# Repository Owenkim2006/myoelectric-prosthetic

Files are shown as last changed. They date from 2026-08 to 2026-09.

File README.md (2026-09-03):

# Myoelectric Prosthetic Hand

**BME 261 Final Project** · University of Waterloo · August 2026  

---

## Overview

This project develops a functional myoelectric prosthetic hand for transradial amputees performing demanding tasks. The system converts microvolt-level surface EMG signals into mechanical grip control through three integrated subsystems: a 7-stage analog front-end, non-blocking C++ firmware, and a dog clutch locking mechanism.

Benchmarked against the Cybathlon "Carry Bottles" task — gripping weighted bottles, placing them into a crate, and transporting the load.

---

## System Architecture

```
Surface EMG Electrodes
        │
        ▼
┌─────────────────────────────────────┐
│     7-Stage Analog Front-End        │
│                                     │
│  1. AD623 INA (gain ~101)           │
│  2. Sallen-Key HPF (48 Hz)          │
│  3. Sallen-Key LPF (400 Hz)         │
│  4. Isolation Buffer                │
│  5. Non-Inverting Amp (gain 11)     │
│  6. Peak Envelope Detector          │
│  7. Schmitt Trigger Comparator      │
│                                     │
│  Total gain: ~1,111×                │
└──────────────────┬──────────────────┘
                   │  Digital trigger (0–5V)
                   ▼
        Arduino Microcontroller
        (Non-blocking state machine)
                   │
                   ▼
          Position Servo Motor
                   │
                   ▼
            Dog Clutch
     (locks finger transmission shafts)
                   │
                   ▼
      Passive Spring-Loaded Fingers
```

---

## Electrical Subsystem

The analog front-end processes raw surface EMG signals (10μV–5mV) through a cascaded 7-stage single-supply architecture.

### Signal Chain

| Stage | Component | Function | Key Parameters |
|---|---|---|---|
| 1 | AD623 INA | Differential amplification, CM rejection | Gain ~101, R_G = 1kΩ |
| 2 | Sallen-Key HPF | Remove motion artifacts, electrode drift | f_c ≈ 48 Hz, C = 33nF, R = 1MΩ / 10kΩ |
| 3 | Sallen-Key LPF | Remove high-frequency noise | f_c ≈ 400 Hz, R = 20kΩ, C = 12nF / 33nF |
| 4 | Buffer (follower) | Isolation — prevent impedance loading | Unity gain |
| 5 | Non-inverting amp | Secondary voltage gain | Gain = 11, R_in = 10kΩ, R_f = 100kΩ |
| 6 | Peak detector | Rectify AC bursts to DC envelope | Active diode-capacitor |
| 7 | Schmitt trigger | Clean binary output to Arduino | Hysteretic comparator |

**Total system gain: ~1,111×**

### Virtual Ground

A buffered voltage divider (2× 10kΩ) creates a stable Vcc/2 reference, enabling single-supply operation. The reference automatically scales with battery voltage — no recalibration needed when switching between lab supply and battery.

### Power

- Lab: regulated DC supply (5V)
- Portable: dual 4×AA packs in parallel (~6V, doubled current capacity)

### Frequency Response

Measured passband: 48–400 Hz. Overdamped filter design produces gradual roll-off at corner frequencies.

---

## Firmware

Written in C++ on Arduino. Non-blocking time-domain state machine — no `delay()` calls.

### State Machine

```
         ┌─────────────────┐
         │      IDLE       │
         └────────┬────────┘
                  │ Edge detected on input pin
                  ▼
         ┌─────────────────┐
         │  BURST ACTIVE   │◄──────────────┐
         │  (timing burst) │               │ Still toggling
         └────────┬────────┘               │
                  │ Duration ≥ 500ms        │
                  ▼                        │
         ┌─────────────────┐               │
         │    ACTUATE      │               │
         │  Toggle servo   │               │
         │  Set lock flag  │               │
         └────────┬────────┘               │
                  │ Signal static > 400ms   │
                  ▼                        │
         ┌─────────────────┐               │
         │  RESET LOCKOUT  │───────────────┘
         │  Clear flags    │
         └─────────────────┘
```

### Key Parameters

| Parameter | Value | Purpose |
|---|---|---|
| `activityWindow` | 500 ms | Minimum contraction duration — rejects twitches and noise spikes |
| `quietTimeout` | 400 ms | Rest period required before next trigger |
| Servo open | 135° | Dog clutch disengaged — fingers free |
| Servo closed | 150° | Dog clutch engaged — fingers locked |

### Why these values?

The 500ms window was chosen to eliminate false triggers from static shocks, brief muscle twitches, and electrical noise while remaining responsive enough for intentional grips. The 400ms quiet timeout prevents rapid re-triggering during a single sustained contraction. Servo angles are software-clamped to prevent mechanical binding and the 2.5A stall current observed near 170°.

---

## Mechanical Subsystem

- **Fingers:** Two interconnected phalange sections (base + top) coordinated by sprockets, chains, and gears
- **Actuation:** Passive spring loading — fingers open when pressed against object geometry
- **Locking:** Dog clutch controlled by position servo — mechanically retains grip with zero steady-state motor current
- **Structure:** Laser-cut plywood with box-joint connections, aluminum axles

### Finger Movement

When the hand contacts an object, friction and reaction forces passively open the fingers to conform to the object geometry. The internal spring tension closes the fingers around the object. On muscle activation, the servo engages the dog clutch, locking the transmission shafts and holding the grip position.

---

## Repository Structure

```
myoelectric-prosthetic/
  firmware/
    prosthetic_control.ino     # Arduino C++ state machine
    flowchart.png              # Firmware flowchart
  electrical/
    bodeplots.png             # Bode plots
    schematic.png              # Full system schematic
    falstad_diagram.txt                # Falstad simulation export
  pcb/
    gerbers/                   # Fabrication files
    prosthetic_pcb.kicad_pcb   # KiCad board file
    prosthetic.kicad_sch       # KiCad schematic
    bom.csv                    # Bill of materials
  mechanical/
    presentation.pdf
  docs/
    BME261_Final_Report.pdf    # Full project report
    bill_of_materials.pdf      # List of parts
```

---

## Running the Falstad Simulation

1. Open [Falstad Circuit Simulator](https://www.falstad.com/circuit/)
2. Click **File → Import from Text**
3. Paste the contents of `electrical/falstad/circuit.txt`
4. Press **Run** to simulate the signal conditioning pipeline

---

## Results

| Metric | Result |
|---|---|
| Signal passband | 48–400 Hz |
| Total analog gain | ~1,111× |
| EMG input range | 10μV–5mV |
| Output range | 0–5V (Arduino compatible) |
| Trigger delay | 500ms (intentional) |
| Servo travel | 135°–150° |
| Cybathlon task | Successfully demonstrated |
| PCB | 2-layer through-hole, 0.4mm signal / 0.8mm power traces |
| Ground | Solid B.Cu copper pour, thermal relief on all pads |
| DRC | 0 errors, 0 unconnected items |

---

## Limitations & Future Work

- **Materials:** PETG components and superglue connections loosened during testing. Future: engineering-grade heat-resistant materials, pinned dog clutch connection
- **Firmware:** 500ms window reduces responsiveness. Future: continuous ADC sampling with digital moving-average filter, shorter activation window
- **Electrical:** Hand-soldered perfboard susceptible to EMI and stray capacitance. Future: multi-layer SMD PCB, LDO regulator for analog supply, buck-boost for servo
- **Power:** Unregulated battery causes reference drift as charge depletes. Future: dedicated LDO for analog front-end
- **Mechanical:** Smooth plastic palm reduces friction on objects. Future: compliant grip surface material

---

## Built With

- **Electrical:** AD623, TL072/TL082 op-amps, discrete passives
- **Simulation:** [Falstad Circuit Simulator](https://www.falstad.com/circuit/)
- **PCB:** KiCad
- **Mechanical:** Autodesk Fusion 360, laser-cut plywood, PETG 3D printing
- **Firmware:** Arduino (C++)
- **Course:** BME 261 — Biomedical Design, University of Waterloo

---

## Authors

- Owen Kim — Electrical subsystem, firmware, PCB design
- Adithi Nagarajan — Mechanical subsystem
- Hilda Zhang — Mechanical subsystem

---

## License

MIT — free to use, adapt, and build on with attribution.

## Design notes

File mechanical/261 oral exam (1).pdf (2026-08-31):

# BME 261 Oral Exam

Professor: Calvin Young

Owen Kim (21120590)

Adithi Nagarajan (21128471)

Hilda Zhang (21144079)

August 13th

# I. User and Scope

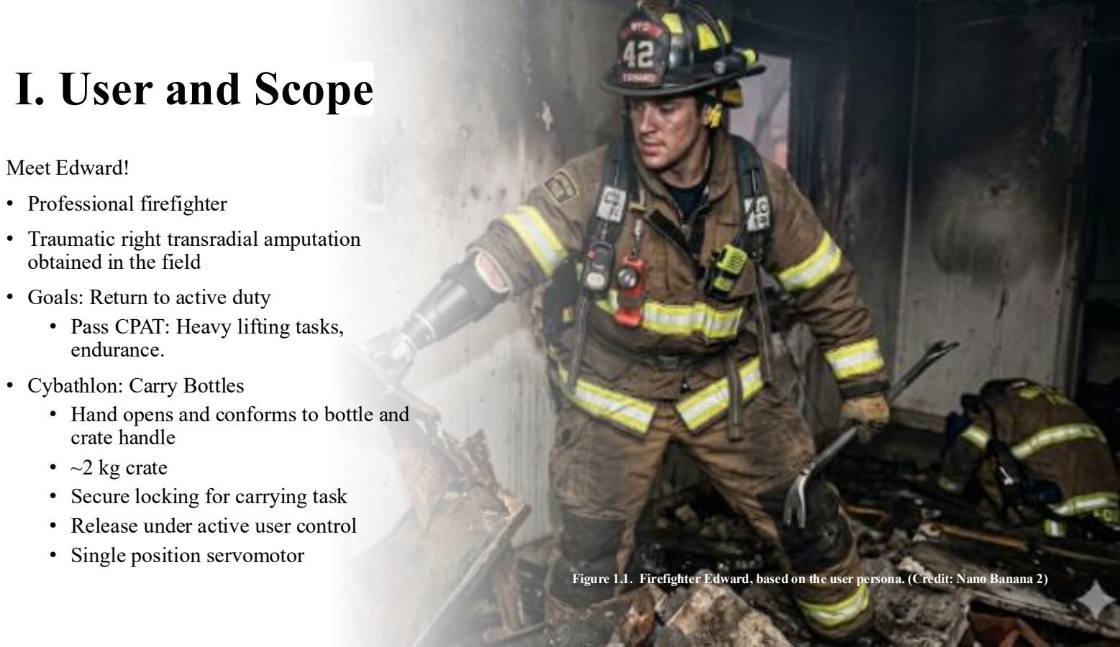
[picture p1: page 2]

Meet Edward!

- Professional firefighter
- Traumatic right transradial amputation obtained in the field
- Goals: Return to active duty
- Pass CPAT: Heavy lifting tasks, endurance.
- Cybathlon: Carry Bottles
- Hand opens and conforms to bottle and crate handle
- ~2 kg crate
- Secure locking for carrying task
- Release under active user control
- Single position servomotor

Figure 1.1. Firefighter Edward, based on the user persona. (Credit: Nano Banana 2)

# II. Mechanical Subsystem

A B

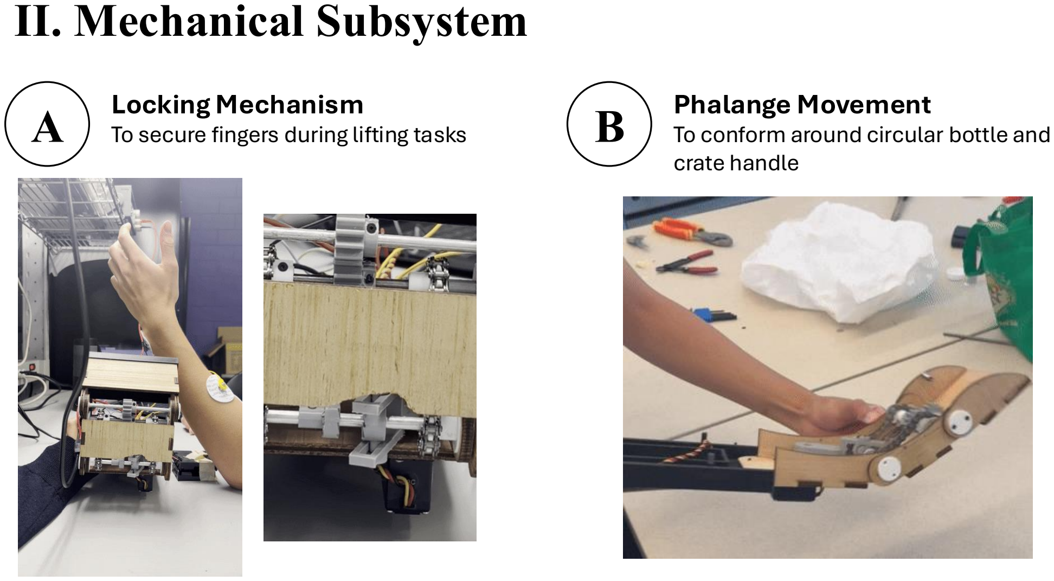
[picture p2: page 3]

# Locking Mechanism

## To secure fingers during lifting tasks

# Phalange Movement

## To conform around circular bottle and crate handle

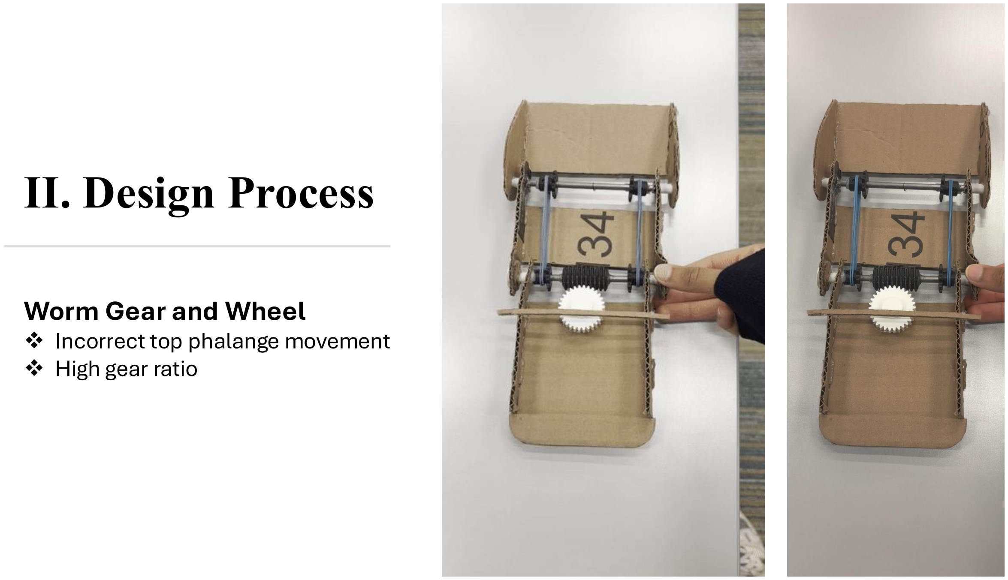
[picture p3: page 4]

# II. Design Process

# Worm Gear and Wheel

## v Incorrect top phalange movement v High gear ratio

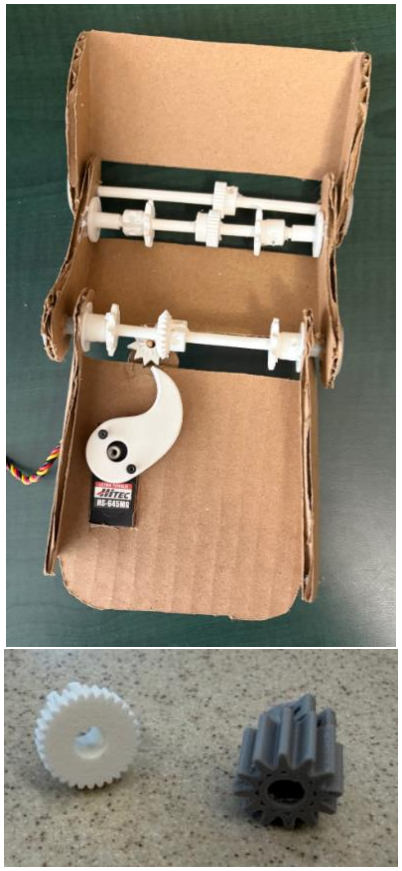
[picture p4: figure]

# II. Design Process

# Bevel Gears

## - Additional axle to correct phalange movement - Bevel gears used to adjust ratio - Unsecure locking mechanism - Gear slipping

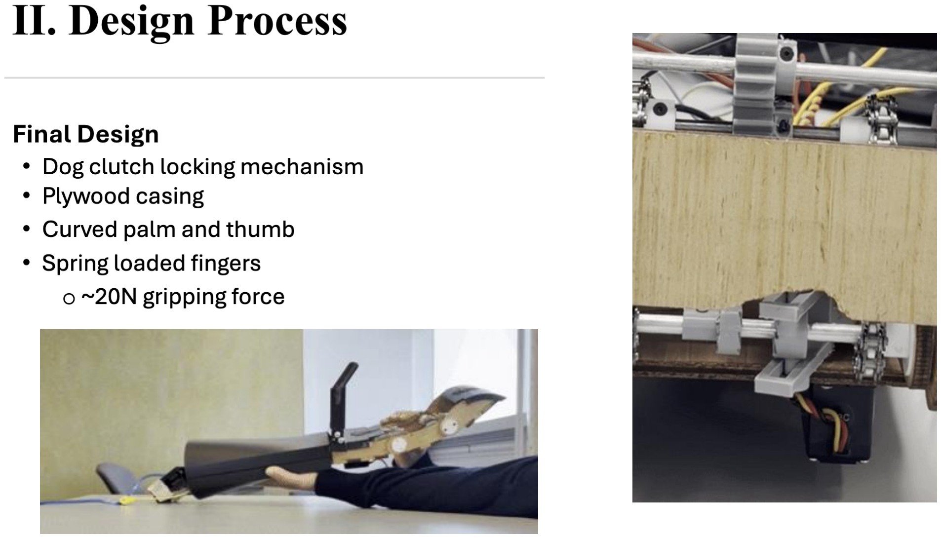
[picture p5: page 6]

# II. Design Process

# Final Design

## - Plywood casing - Dog clutch locking mechanism - Curved palm and thumb - Spring loaded fingers - ~20N gripping force

# III. Signal Processing and Firmware Subsystem

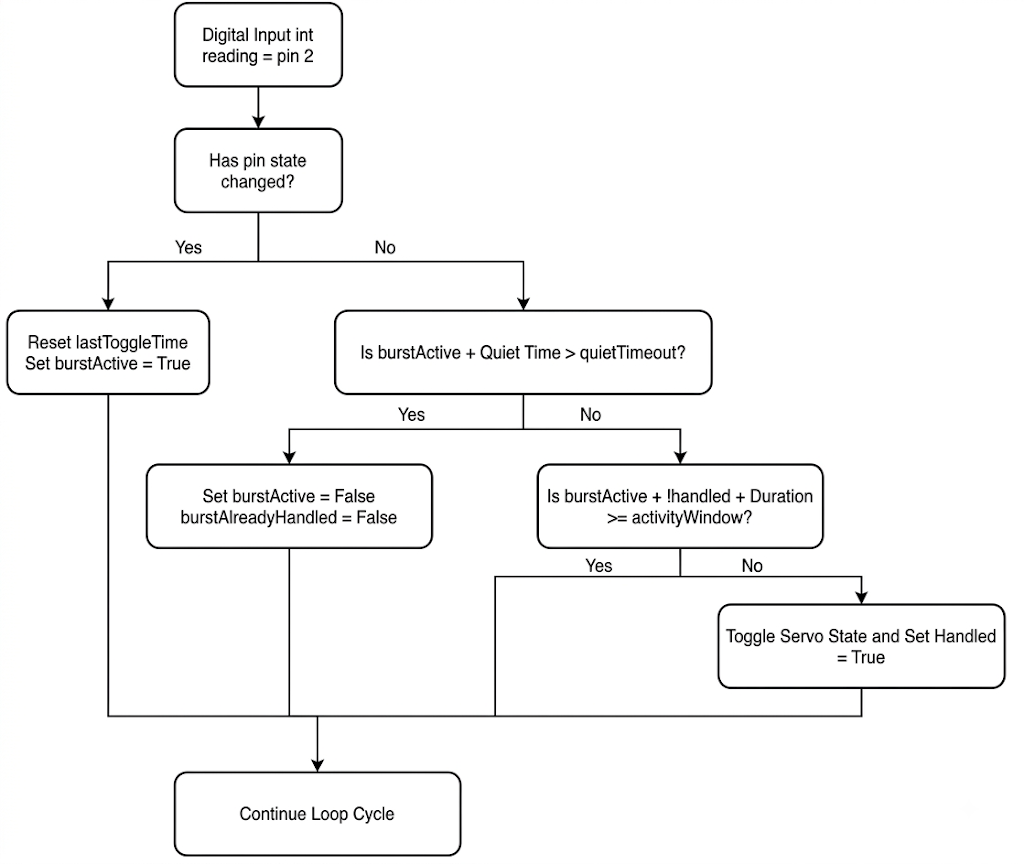
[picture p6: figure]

Figure 3.1: Time-domain burst-detection algorithm flowchart.

Requirements:

- Prevent accidental contraction from

high-frequency noise

- Activity window of ~0.5 seconds
- Quiet period of 400 ms
- Servo sweep angles: 135 degrees (lock

open) and 150 degrees (lock closed)

# IV. Electrical Subsystem

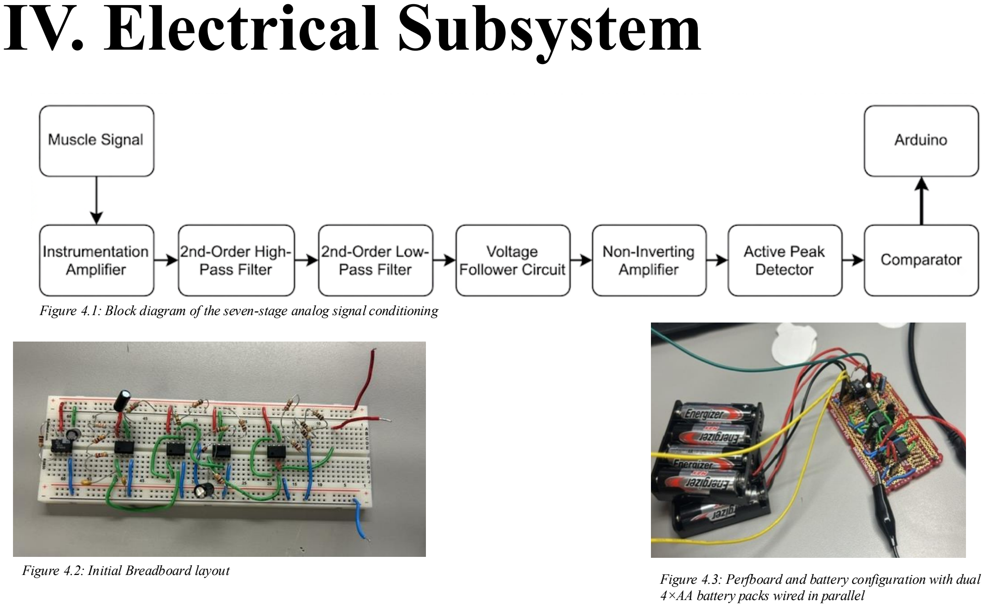
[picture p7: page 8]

Figure 4.1: Block diagram of the seven-stage analog signal conditioning

Figure 4.3: Perfboard and battery configuration with dual 4×AA battery packs wired in parallel

Figure 4.2: Initial Breadboard layout

# IV. Electrical Subsystem

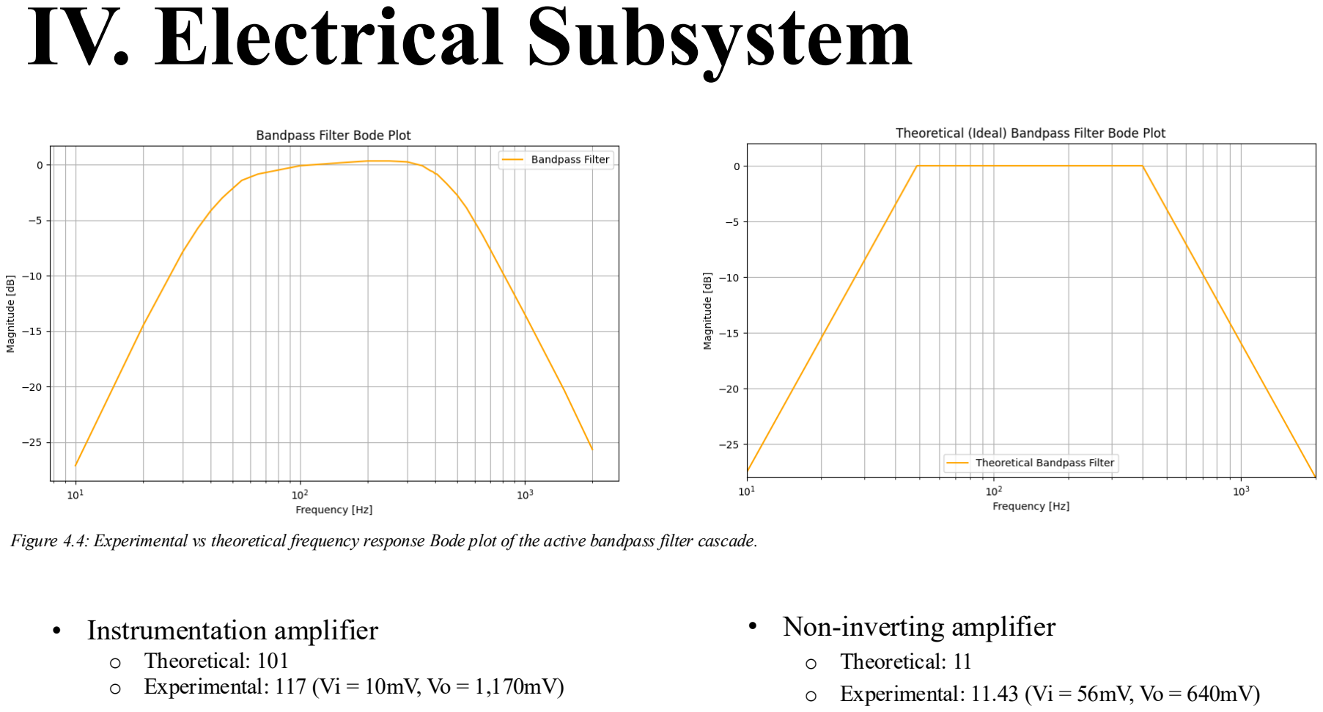
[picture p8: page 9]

Figure 4.4: Experimental vs theoretical frequency response Bode plot of the active bandpass filter cascade.

- Non-inverting amplifier
- Theoretical: 11
- Experimental: 11.43 (Vi = 56mV, Vo = 640mV)
- Instrumentation amplifier
- Theoretical: 101
- Experimental: 117 (Vi = 10mV, Vo = 1,170mV)

# V. Task Completion

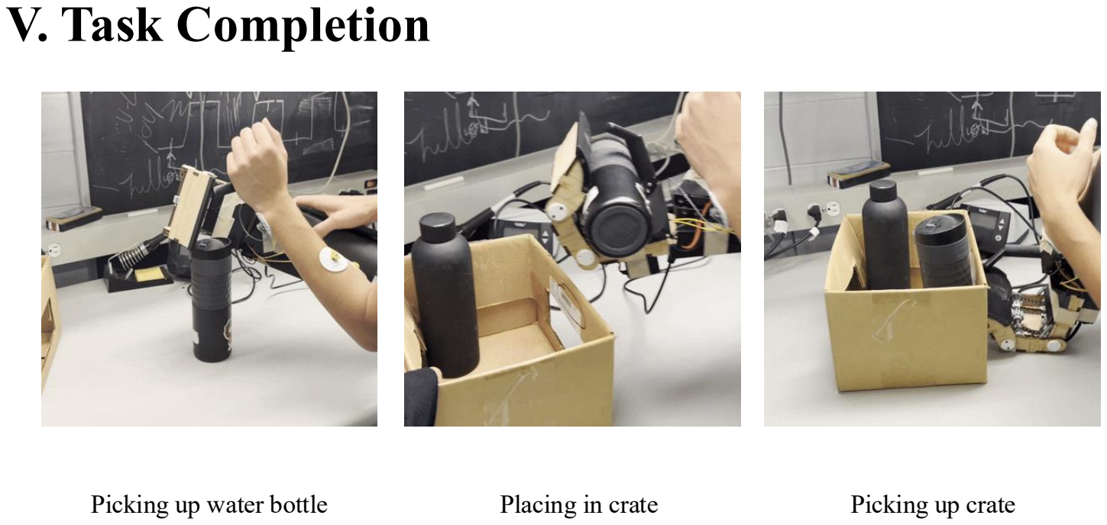
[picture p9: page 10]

Picking up water bottle | Placing in crate | Picking up crate

# V. Recommendations

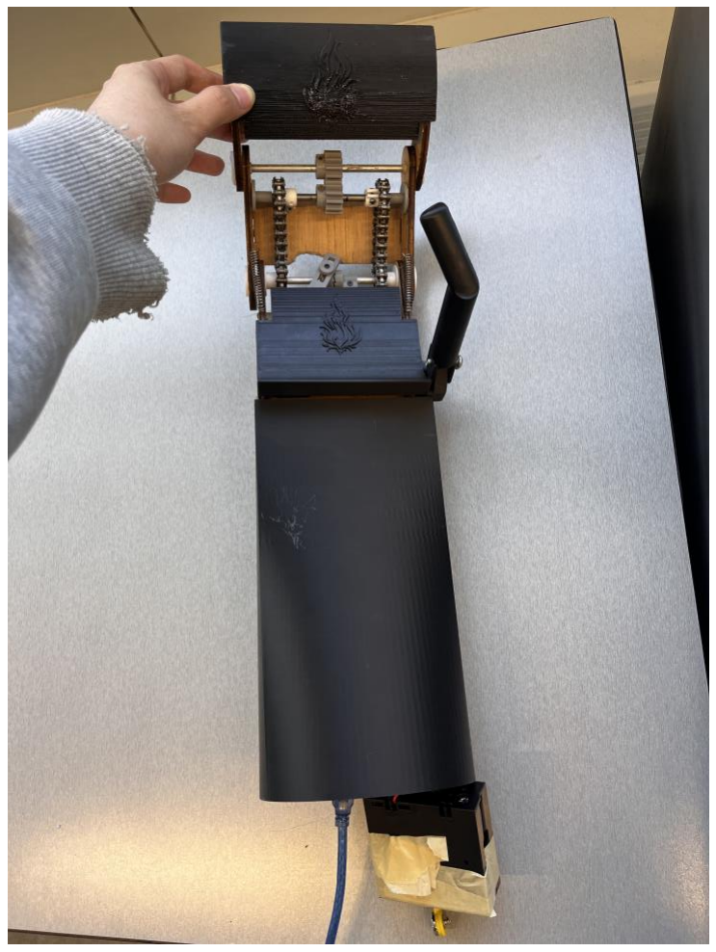
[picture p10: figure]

### - Mechanical

- Materials
- Heat resistance
- Durability
- Comfort
- Heat resistance
- Durability

### - Electrical and Firmware

- The 500 ms activity window
- Unregulated battery supply

# VI. Recommendations

# Thank You!

# Q & A for BME261

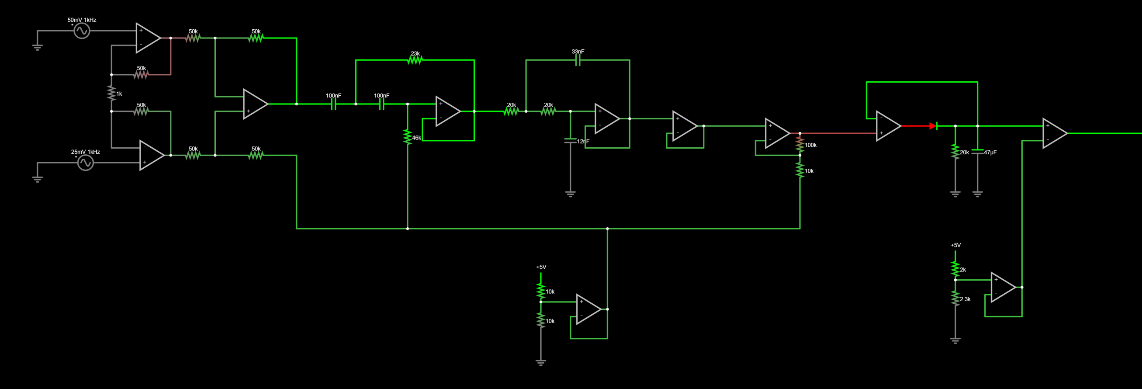
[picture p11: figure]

# Q & A for BME294L

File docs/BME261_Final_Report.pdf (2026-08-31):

BME 261 Final Report

Development of a Ruggedized Myoelectric Prosthetic Hand for High-Load Operational

Tasks in Heavy-Duty Environments

Owen Kim (21120590), Adithi Nagarajan (21128471), and Hilda Zhang (21144079)

Professor: Calvin Young

August 5

th, 2026

Executive Summary

This project aimed to develop a practical myoelectric arm for Edward, a firefighter who experienced a right transradial amputation following a fire-related accident and wishes to return to fieldwork. The selected Cybathlon-inspired tasks included gripping water bottles, placing them into a crate, and carrying the crate. These tasks represent common gripping and lifting challenges in firefighting. The main design requirements included reliable gripping, simple user control, stability under load, passive load retention, and operation using only one motor.

The final design consists of a thumb and four fingers combined into two interconnected sections. These sections can bend around an object to create a more adaptable grip. The mechanical subsystem uses sprockets, chains, gears, rotating shafts, and springs to coordinate the movement of the finger sections. A dog clutch controlled by a servomotor lock releases the mechanism, allowing the hand to maintain its grip without requiring continuous motor operation.

The signal-processing and electrical subsystems convert the user’s forearm muscle activity into a control signal for the servomotor. The circuit consists of an instrumentation amplifier, a band-pass filter, a buffer, a non-inverting amplifier, a peak detector, and a comparator. Together, these stages amplify and process the EMG signal and determine whether the muscle activation exceeds a preset threshold. The firmware then moves the servomotor between two preset positions to engage or disengage the dog clutch.

Following several rounds of design, prototyping, and testing, the team completed an integrated prototype that successfully demonstrated the core gripping, locking, and EMG-based control mechanisms. However, the prototype was not fully successful as a final solution for the intended firefighting application because it did not meet the required durability, heat resistance, and reliability. Future development should focus on using stronger and more heat-resistant materials, improving mechanical tolerances and connections, reducing the control delay, and conducting additional testing with different objects and loading conditions.

I. Introduction

Edward is a professional firefighter who experienced a right transradial amputation approximately 14 months ago and hopes to return to active duty (Figure 1.1). Although he is new to prosthetic control systems, he is familiar with advanced rescue equipment and motivated to learn. However, many existing upper-limb prostheses are designed mainly for appearance or daily activities and may not meet the demands of firefighting.

Myoelectric arms are electrical power devices. They use electrodes over the residual forearm muscles to detect signals produced during muscle contraction [1]. These signals are processed to control motor-driven functions such as gripping and releasing [1]. This allows the user to operate the arm using their remaining muscles, but sweat, electrode movement, electrical noise, and sudden movements may reduce control reliability.

Firefighters work in environments involving heat, water, humidity, soot, dust, and impact, and may suddenly shift from rest to intense physical effort [2]. Edward therefore needs an arm that responds quickly, tolerates forceful movements, and securely holds heavy or uneven objects [3]. An unreliable grip could cause dropped equipment or lead to overuse of his unaffected arm, contributing to shoulder fatigue and lower-back pain. His main needs include heat and impact resistant construction, rapid attachment, reliable gripping, passive load retention, and a wrist that can lock [3]. The arm must also be simple to control during emergencies and capable of supporting the variety of gripping, lifting, and carrying tasks involved in firefighting.

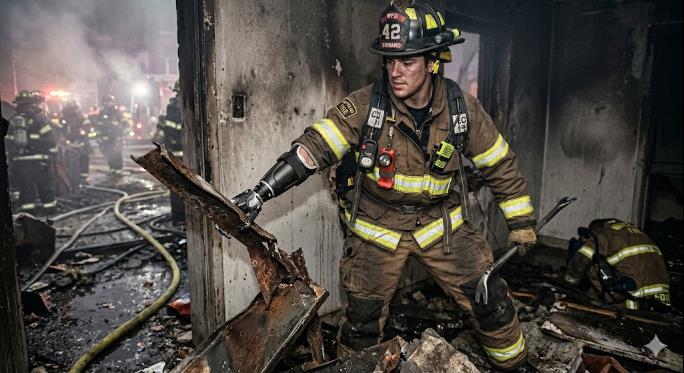
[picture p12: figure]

Figure 1.1. An AI-generated image of firefighter Edward, our persona, in the firefighting field, ready to

rescue residents trapped in the building. (Credit: Nano Banana 2)

To represent the variety of lifting and carrying tasks associated with firefighting, our team benchmarked the project against the Cybathlon "Carry Bottles" task, which requires picking up weighted bottles, placing them into a crate, and transporting the load under time pressure [4]. The primary goal was to develop a functional myoelectric hand capable of passively opening and conforming around bottle and crate handle geometries, securely locking around the objects, and releasing them under active user control. To maximize energy efficiency and safety, the hand was designed to retain loads mechanically without requiring continuous motor torque once locked. The scope was governed by course constraints, most notably the restriction to a single position servomotor, which prevented independent finger driving. Secondary requirements identified for the persona, such as rapid socket attachment, wrist rotation, thermal shielding, and temperature feedback, were excluded from this prototype phase and are recommended for future development. Production methods and materials were selected primarily to demonstrate core mechanical and electrical functions within the course timeline.

The mechanical subsystem includes a thumb, a palm, and four fingers combined into top and base phalanges blocks. Because only one motor could be used, the servomotor was reserved for controlling the locking mechanism rather than directly driving the fingers. When the hand is pressed downward against the water bottle, friction and contact forces cause the finger sections to open and conform to its shape. For the crate task, the hand is pushed against the rim of the crate, and the resulting reaction force passively forces the fingers to stretch and conform to the geometry of the handle. Chains, sprockets, gears, and rotating shafts coordinate the movement of the finger sections. When forearm flexion is detected, the position servomotor actively engages the dog clutch. This prevents the transmission shafts from rotating and locks the fingers in their current position. Once engaged, the dog clutch mechanically retains the grip without requiring continuous motor torque. When the servomotor disengages the clutch, the shafts can rotate again, allowing springs to return the finger blocks toward their initial positions. The plywood structure and casing also act as physical stops that restrict the maximum rotation angles.

The electrical subsystem detects the user’s forearm muscle activity through an EMG input. Because the original EMG signal is small and contains noise, it passes through an instrumentation amplifier, a band-pass filter, a non-inverting amplifier, a peak detector, and a comparator. These stages amplify and condition the signal before producing an output that can be interpreted by the microcontroller.

The firmware reads the processed control signal and moves the servomotor between two preset positions. At one position, the servomotor engages the dog clutch to lock the mechanical system. At the other position, it disengages the dog clutch, allowing the springs to return the finger sections to their initial configuration. In this way, the three subsystems convert muscle activation into a mechanical locking or releasing action while using only one motor.

II. Mechanical Subsystem

The solution’s mechanical design focused on 2 main objectives. First, the fingers must

move continuously from a flat, open position, to a closed circular position (Figure 2.1). This

addresses the prosthetic constraint of needing to conform around a circular object, such as a

water bottle or handle for carrying. The second objective is that the fingers must lock into place,

at a desired position. This is necessary since the prosthetic must be able to carry an object.

Without a locking mechanism, the weight of an object will manually push the fingers back,

unintentionally releasing it. This mechanism is controlled by a position servo integrated into the

electrical subsystem, giving the user control of object release.

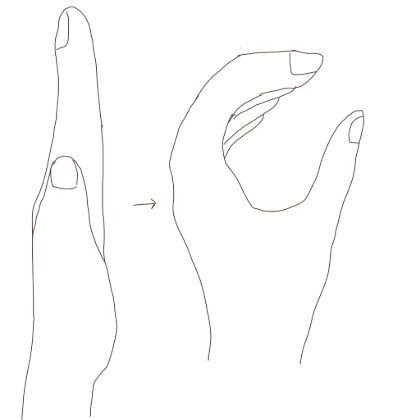
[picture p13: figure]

Figure 2.1. Visualization of hand movement from open to closed position.

To address both objectives, an initial prototype was designed (Figure 2.2). In the first

design, finger movement is motor driven. It incorporates a ratchet that is rotated by a motor.

During rotation, strings threaded through the four fingers are pulled or released, opening and

closing the fingers. To achieve the locking constraint, a pawl is used to prevent ratchet rotation

and consequently finger movement in the outward direction. This prevents the fingers from being

pushed backwards while carrying tasks. To unlock the mechanism and allow the prosthetic to

flatten back out, and eccentric cam is rotated to engage the pawl and lift it off the ratchet.

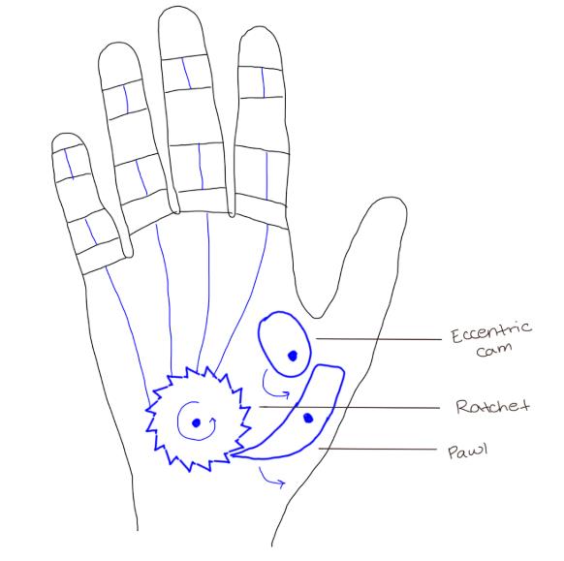
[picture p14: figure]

Figure 2.2. Initial sketch of prosthetic design. Motor driven ratchet pulls on strings to open and close

fingers. Pawl utilized for locking mechanism and released through rotation of eccentric cam.

Upon receiving feedback through the gallery walk, extensive changes were made to this

design. Since all four fingers move simultaneously, a question was raised about the benefit of

having separate fingers. Upon analyzing this feedback, future iterations adapted to having

connected fingers to allow for greater strength and simpler mechanics due to the individual and

larger finger component. Other feedback surrounded the locking mechanism, and it was apparent

that a single motor could not rotate both the ratchet and the eccentric cam in two different ways

as initially intended. The ratchet needs continuous rotation, while the eccentric cam should only

be rotated in and out of place to lock or unlock finger position. So, this whole mechanism was

updated.

After analyzing all the feedback and revisiting the constraints, a second iteration was

designed (Figure 2.3). Due to the singular motor limitation, the motor is used solely for locking

mechanisms. The pawl, screwed directly into the position servo, can be moved between two set

positions. When the pawl engages with the teeth of the worm wheel, the fingers are locked into

place. When the pawl moves away from the worm wheel, the fingers are free to move freely. As

a result, finger movement is mechanical, rather than motor driven. The overall design uses spring loaded finger that holds the fingers in a closed position at rest (Figure 2.4). When wrapped

around a circular object, like a water bottle or handle, the fingers are manually pushed back,

stretching the spring. Upon user activation through a forearm muscle contraction, the fingers will

be locked in place at their current position, preventing the fingers from being flattened further.

This allows the object to be carried. The other major change made to this iteration is in how the

fingers move. Rather than being controlled by pulling strings, sprockets and bike chains are used

to connect the palm, base phalange, and top phalange. They are connected such that when the

base phalange is pushed back, the top phalange also flattens. This allows the prosthetic to move

continuously between a semi-closed fist, optimal for fitting around a circular object, and a flat

palm, allowing for objects of multiple sizes to be carried. Since the tasks specifically centers

around circular objects, the inside of the hand contains a curved surface to provide a better fit.

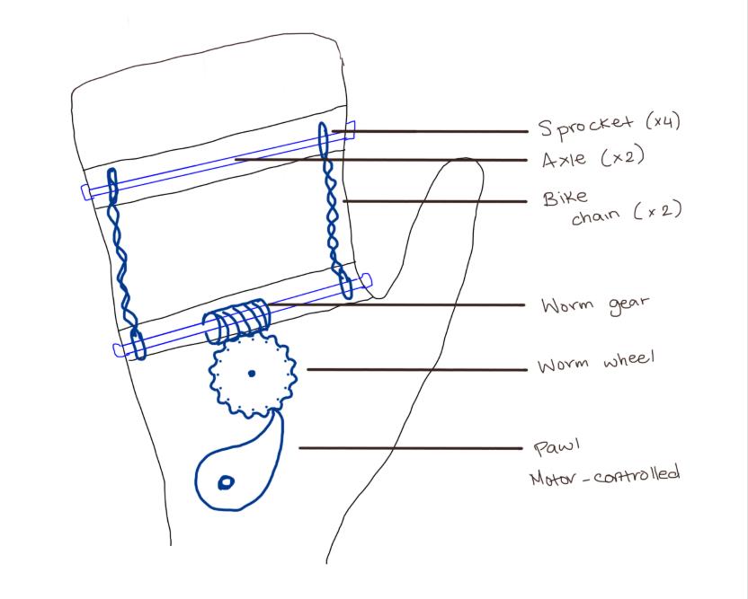
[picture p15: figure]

Figure 2.3. Sketch of the second iteration.

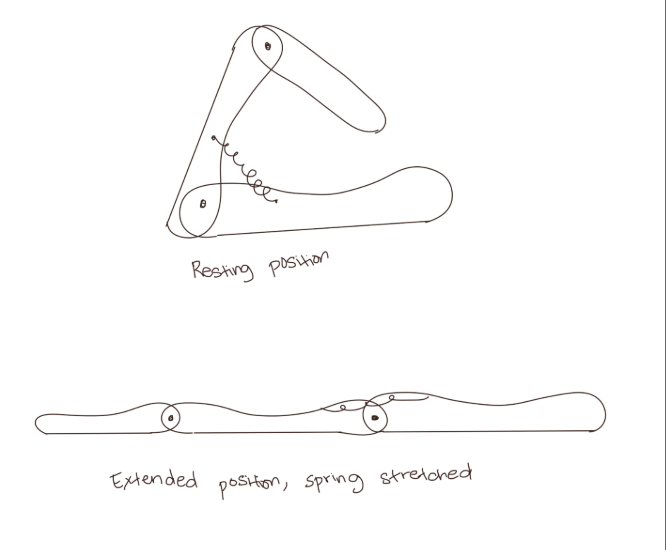
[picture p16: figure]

Figure 2.4. Spring loaded fingers. Held in a semi-closed fist at rest. The springs are manually stressed to

flatten the hand.

To test the efficacy of this design, a low fidelity prototype was created (Figure 2.5).

Cardboard was used to create the casing of the prosthetic, while the internal components were

3D printed for rapid production. Upon inspection of this physical model, various limitations were

discovered. Due to the gear ratio between the worm gear and worm wheel, the full movement of

the prosthetic between the open and closed position caused very little rotation of the worm

wheel. As a result, the pawl was ineffective at stopping movement, since the mechanism relied

on stopping the worm wheel in a specific position. To address this, bevel gears were used since

their gear ratio can be altered. Another issue was observed in the finger movement. As the base

phalange is moved inwards towards the closed position, the intention was for the top phalange to

also move inwards. However, due to the chain connected between the sprockets for each

phalange, the top phalange moved in the opposite direction of the bottom one. To fix this issue,

additional gears were added in future iterations to change the direction of rotation.

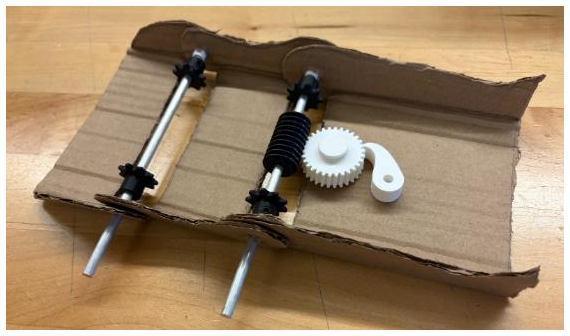
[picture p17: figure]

Figure 2.5. Physical prototype of second iteration. Uses pawl and worm wheel to lock phalanges in place.

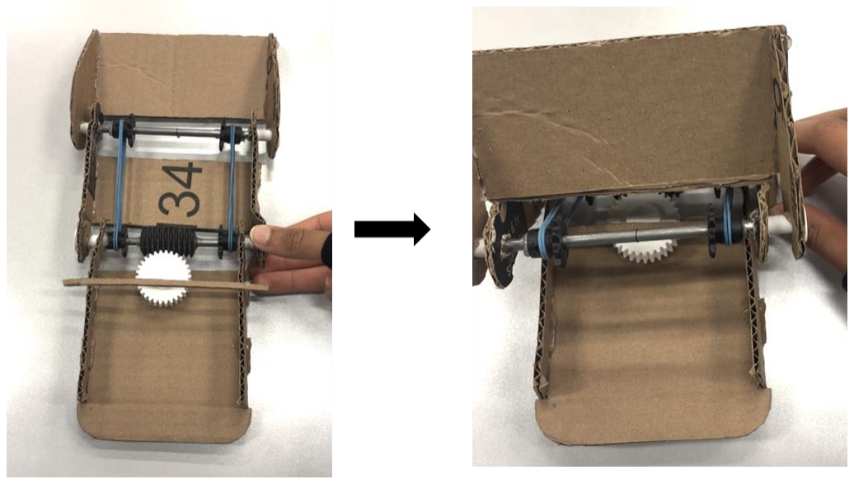
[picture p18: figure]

Figure 2.6. Error in finger movement. As the bottom phalange is moved into the closed position, the top

phalange incorrectly flips upwards.

After troubleshooting the first physical model, a third iteration was prototyped (Figure

2.7). While this prototype fixed the identified problems, other issues arose. When the fingers

were spring loaded, the torque caused slipping in two key areas, the interface between the bevel

gears and the pawl, and gears connected to the top and base phalange. This prevented the fingers

from locking reliably. To address the gear slippage between the two phalanges, the gear module

was increased (Figure 2.8). The thicker tooth profile increased contact area and stability. To

improve the reliability of a locking mechanism, the final iteration used a dog clutch. This preserves the concept of using the position servo to move a component between locked and

unlocked positions. However, it greatly increases the surface area, creating a stronger grip on the

base axle to stop movement.

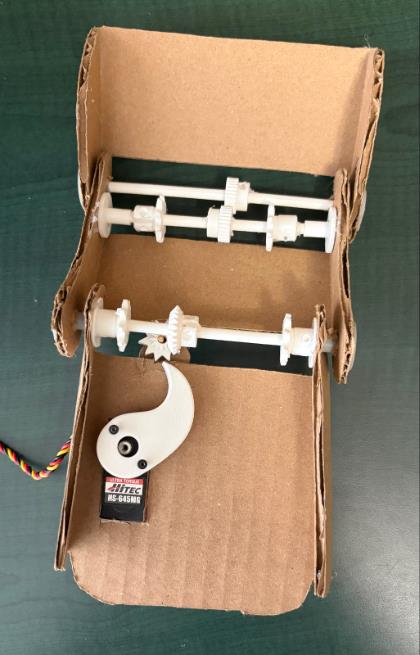
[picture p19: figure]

Figure 2.7. Physical prototype of the third iteration. Uses bevel gears to address the gear ratio problem.

Uses additional gears to change the direction of rotation for the top phalange.

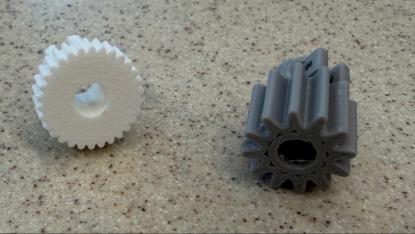
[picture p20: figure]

Figure 2.8. Increased gear module to prevent slipping between the top and base phalange.

Through analyzing the limitations revealed by the first 2 low fidelity prototypes, a final

prototype was constructed (Figure 2.9). Laser cut plywood with box joint connections were used to increase the mechanical strength of the prosthetic casing. Additionally, aluminum axles

replaced the steel axles used in the first physical prototype to decrease the overall weight while

maintaining sufficient strength. A casing for the electrical subsystem was added to allow for

better integration. Overall, this design addressed the defined constraints through its ability to

control the movement of the base and top phalange between the flat and closed positions and

lock the fingers in a desired position (Figure 2.10).

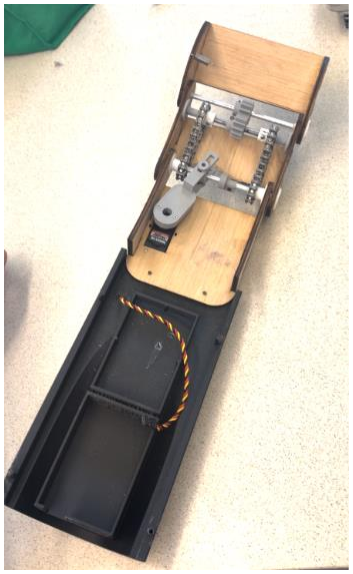
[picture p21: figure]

Figure 2.9. Final prosthetic prototype. Includes improved gear module, dog clutch locking

mechanism, plywood base, and electrical casing.

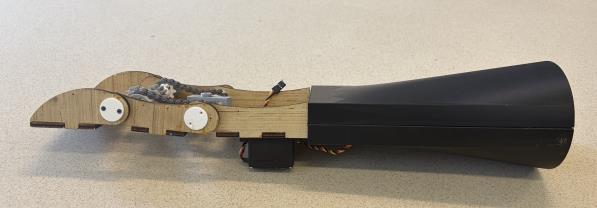
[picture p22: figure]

↓

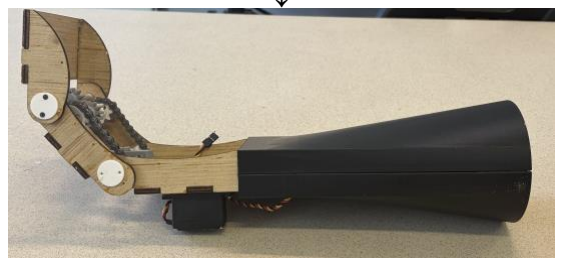
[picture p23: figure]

↓

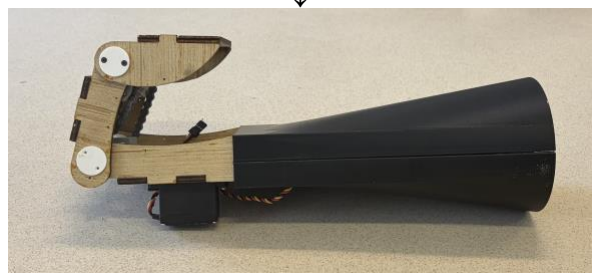
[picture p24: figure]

↓


Figure 2.10. Controlled movement of the base and top phalange between the closed and flat positions.

When the base phalange is moved, internal gears move the top phalange accordingly.

III. Signal Processing and Firmware Subsystem

Surface EMG signals captured during muscle contraction are inherently noisy, highly

stochastic, and prone to rapid high-frequency fluctuations. Raw analog comparator outputs can

chatter near the decision threshold due to motion artifacts or minor muscle twitches, which can

cause erratic servo motor jitter, false triggering, or mechanical binding, making user control

impossible without secondary signal smoothing [5].

The goal of the firmware subsystem is to convert analog signals into smooth, predictable

servo motor actuation. The firmware must reliably distinguish intentional, sustained muscle

contractions from transient noise spikes while enforcing safe motor travel bounds. To achieve

this, the control logic leverages contextual timing cues tailored to the specific analog

performance characteristics and non-idealities of the electrical subsystem.

To ensure optimal performance and use safety, the firmware subsystem was developed

around four operating constraints First, to prevent accidental contraction from high-frequency

noise, or muscle twitches, the algorithm requires an intentional muscle contraction to persist

continuously for an activity window of 500 milliseconds (~0.5 seconds). While this introduces a

half-second processing delay, it prioritizes false-trigger immunity and trigger confidence over

hyper-responsiveness. Next, to ensure the motor stops after a contraction, the system must

enforce a mandatory quiet period of 400 milliseconds where no pin toggling occurs before

considering a muscle burst finished, preventing rapid, erratic re-triggering during a single

contraction. Moreover, Servo sweep angles must be strictly constrained in software between 135

degrees (hand open) and 150 degrees (hand closed) to prevent physical joint binding, gear

stripping, or the extreme 2.5A stall current draws observed near 170 degrees. Finally, the logic

must implement a state lockout to ensure that a single sustained muscle flex results in exactly

one state toggle rather than continuous rapid cycling.

The embedded firmware is written in C++ and runs on an Arduino microcontroller.

Rather than tracking raw analog amplitude or relying on hardware interrupts, the software

evaluates muscle activity using a non-blocking, time-domain state machine. The control

algorithm continuously polls the digital output of the hardware comparator stage to monitor

signal activity. When a user flexes a muscle, high-frequency voltage fluctuations pass through

the comparator, causing the digital input pin on the Arduino to rapidly toggle between zero volts and five volts. Rather than treating a single rising voltage edge as an immediate trigger

command, which would leave the hand vulnerable to static shocks or brief muscle twitches, the

system treats state changes as candidate activity. Upon detecting any state transition, the program

starts an internal timer to measure the duration of the contraction. The execution loop then

continuously evaluates two simultaneous conditions. The first condition is the active contraction

handling, if high-frequency toggling persists continuously for at least 500 milliseconds

(activityWindow), the algorithm recognizes a deliberate, sustained muscle contraction. It flips

the internal state of the hand, commands the servo motor to move to its target angle, and

immediately sets an execution lock to prevent continuous re-triggering during the remainder of

the flex. The second condition handles the rest identification, where if the signal stops toggling

and remains static for longer than 400 milliseconds (quietTimeout), the algorithm determines

that the muscle has returned to a relaxed state. It clears the execution lock and resets the state

machine so the hand is ready to receive the next intentional contraction. This dual-timer

architecture effectively acts as a digital state-machine filter, absorbing threshold noise from the

analog front-end and translating binary muscle activity into smooth, predictable hand control.

The flow chart outlining the firmware logic is showcased in figure 3.1


Figure 3.1: Time-domain burst-detection algorithm flowchart. The state machine monitors input pin edge

transitions to track candidate muscle bursts, qualifying intentional contractions after a 500 ms

continuous activityWindow and resetting the execution lock once a 400 ms quietTimeout rest phase is

observed.

As shown in figure 3.2, the execution loop constantly polls inputPin. By comparing the

current reading against lastReading, the code detects toggling across both signal edges. If activity

begins while burstActive is false, the program records burstStartTime and initializes the

candidate burst tracking.


Figure 3.2: Edge State Detection and Burst Initialization

While a burst is active, the program continuously verifies whether the muscle contraction

is sustained long enough to qualify as a deliberate input. As detailed in figure 3.3, once the

duration (now - burstStartTime) meets or exceeds activityWindow (500 ms) and

burstAlreadyHandled is false, the firmware toggles servoIsFlexed, writes the new target angle to

the motor, and sets burstAlreadyHandled = true.


Figure 3.3: Burst Duration Verification and Servo Actuation

Finally, when the user relaxes their arm, signal toggling stops. Once the time elapsed

since the last edge transition (now - lastToggleTime) exceeds quietTimeout (400 ms), the

algorithm clears burstActive and burstAlreadyHandled, resetting the control loop to accept the

next muscle contraction. This complete firmware state machine successfully bridges the analog

front-end and mechanical actuation, providing a robust, noise-immune software filter that

guarantees safe, repeatable prosthetic hand control.

IV. Electrical Subsystem

Surface EMG signals originate as microvolt to low-millivolt physiological action

potentials generated across skeletal muscle fibers during depolarization. When recorded non-

invasively via surface skin electrodes, these signals present extreme conditioning challenges.

Typical EMG amplitudes range from merely 10μV to 5mV peak-to-peak, requiring substantial

low-noise amplification before they can be processed by standard microcontroller digital logic.

Furthermore, these microvolt biopotentials are buried beneath significant environmental and

physiological interference. Additionally, low-frequency movement artifacts caused by electrode

displacement or skin stretch introduce severe baseline wander (<20Hz), while broad-band

thermal noise (>500Hz) degrades the clarity of the signal. Beyond signal conditioning, powering

a biomedical mechatronic system introduces severe power quality and ground stability

challenges. While initial benchtop development relies on tethered laboratory DC power supplies,

a truly functional upper-limb prosthetic requires autonomous, portable power. However,

transitioning a sensitive analog signal chain to battery power introduces significant voltage rail

constraints. Ultimately, the design must bridge delicate analog signal extraction with heavy

transient power demands inside a single, portable architecture.

The physical signal conditioning pipeline processes microvolt-level muscle signals

through a cascaded, seven-stage single-supply analog architecture. As illustrated in the block

diagram in Figure 5.1, biopotentials move sequentially through differential instrumentation,

active bandpass filtering, isolation buffering, secondary voltage gain, peak envelope detection,

and threshold comparator stages before interfacing with the microcontroller.


Figure 5.1: Block diagram of the seven-stage analog signal conditioning pipeline, depicting signal flow

from surface electrodes through instrumentation amplification, active bandpass filtering, buffer isolation,

non-inverting gain, peak envelope detection, and comparator logic thresholding.

The physical hardware chain begins with an AD623 instrumentation amplifier connected

directly to surface skin electrodes. Configured with a precision 1k ohm gain resistor, this initial

stage delivers a differential gain of roughly 101, maximizing the common-mode rejection ratio to

suppress ambient 60 Hz mains interference before subsequent amplification. The reference pin of

the instrumentation amplifier is tied directly to a buffered virtual ground midpoint, centering the

output signal swing symmetrically between the power rails. Filtering is accomplished using a

pair of active two-pole Sallen-Key filter networks designed to isolate the clinical

electromyography frequency spectrum. First, the signal enters a Sallen-Key high-pass filter

configured with two 33nF capacitors, a 1M ohm resistor, and a 10k ohm resistor to establish a

corner frequency of approximately 48 Hz at unity gain, aggressively stripping away low-

frequency motion artifacts and electrode drift. The signal then passes into a Sallen-Key low-pass

filter utilizing two 20k ohm resistors, a 12nF capacitor, and a 33nF capacitor to set a high-

frequency cutoff of roughly 400 Hz at unity gain, eliminating out-of-band thermal noise.

Because both filter stages are designed with heavily overdamped quality factors, the transition

around the cutoff frequencies is gradual rather than a sharp, abrupt corner. The theoretical design

response alongside the measured frequency response featuring this overdamped transition shape

is depicted in the Bode plot in Figure 5.2.


Figure 5.2: Experimental frequency response Bode plot of the active bandpass filter cascade. The plot

shows a flat passband gain, with gradual transition roll-offs near the corner frequencies due to heavily

overdamped high-pass and low-pass filter responses.

Following the active filter stages, an operational amplifier voltage follower serves as an

isolation buffer. This buffer prevents input impedance loading from downstream gain stages

from pulling down signal amplitude or shifting the filter corner frequencies. Next, a non-

inverting operational amplifier stage configured with a 10k ohm input resistor and a 100k ohm

feedback resistor provides a secondary voltage gain of 11. Across the first five stages, total AC

analog system gain reaches approximately 1,111 times, converting millivolt-level muscle action

potentials into multi-volt AC signals centered around the virtual ground reference. To prepare the

high-frequency AC muscle bursts for threshold logic evaluation, the signal passes into a peak

envelope detector stage. This active diode-capacitor circuit rectifies and smooths the oscillating

AC waveform into a continuous DC envelope voltage that tracks the amplitude profile of the

muscle contraction. Finally, a Schmitt trigger comparator evaluates this smooth DC envelope

against the secondary voltage divider reference to generate a clean, chatter-free binary logic

signal for the digital input of the Arduino microcontroller. The complete hardware schematic

detailing all component values, op-amp connections, and stage layouts is provided in Figure 5.3.


Figure 5.3: Complete system schematic diagram, breadboard and perfboard showing component values

for the AD623 instrumentation amplifier, Sallen-Key filter networks, buffer, non-inverting amplifier, peak

detector, Schmitt trigger comparator, and virtual ground circuit.

To operate the entire analog front-end from a single positive power source, a virtual

ground buffer creates a stable DC midpoint reference set to half of the supply voltage. Two 10k

ohm metal-film resistors divide the positive supply rail in half, which is then buffered by a low-

impedance op-amp follower. This ratio design guarantees that whether the circuit is powered by

a regulated 5V laboratory supply or a dynamic 6V battery pack, the virtual ground reference

automatically scales to exactly 50 percent of the supply voltage. Additionally, a secondary

voltage divider utilizing 2k Ω and 2.3k Ω resistors was implemented to establish a separate,

dedicated reference voltage tailored specifically for the Schmitt trigger comparator thresholding.

Consequently, no manual threshold recalibration or gain adjustments are required when

switching power sources.

Although initial benchtop development relied on tethered laboratory power supplies,

functional portability testing prompted the introduction of a dual 4xAA battery pack connected

in parallel to provide roughly 6V with doubled current capacity. Under laboratory conditions, a

regulated DC power supply provides superior voltage stability and near-zero rail ripple, making

it ideal for precision analog measurements. For mobile operation, the parallel battery architecture

was designed to provide sufficient current capacity to support motor actuation without dropping

the logic supply below the microcontroller reset threshold, though full-load verification under

simultaneous motor stall conditions remains an unverified limitation of the physical prototype.

Ultimately, this single-supply analog conditioning chain and dynamic virtual ground architecture

reliably extract microvolt muscle biopotentials and convert them into clean control triggers,

bridging delicate biopotential sensing with portable power demands.


Figure 5.4: Physical parallel battery configuration featuring dual 4×AA battery packs wired in parallel

(~6V) to double current capacity for portable system operation.

Ultimately, this seven-stage analog conditioning chain and dynamic virtual ground

architecture reliably extract microvolt muscle biopotentials and convert them into clean control

triggers, bridging delicate biopotential sensing with portable power demands.

V. Conclusion & Recommendations

In conclusion, the prototype met the main functional constraints of the Cybathlon “Carry Bottles” task. The sprocket and chain system moved the base and top phalanges, while the object load stretched the springs and opened the hand. The position motor moved the dog clutch into the locking position and held the hand in place.

The electrical subsystem amplified the muscle signals, stabilized the output, and shifted it into the 0 to 5 V range required by the firmware. The bandpass filter was designed for a frequency range of 48 to 400 Hz. The firmware moved the motor to 135 degrees during forearm extension to disengage the dog clutch and to 150 degrees during flexion to engage it. Requiring the activity condition to remain present for 500 ms also reduced false triggers caused by brief muscle twitches and electrical noise.

However, the prototype did not meet several criteria for firefighting use. The selected materials were not sufficiently heat resistant or resistant to deformation. The gears and sprockets were printed in PETG and attached to the shafts with super glue, causing the mechanism to loosen during testing. This limited its strength and long term durability.

The 500 ms activity window reduced responsiveness and made the gripping operation less intuitive. The hand soldered perfboard also required more enclosure space and used long connections that were more vulnerable to stray capacitance, human error, and electromagnetic interference. In addition, the unregulated battery supply could cause the reference voltage and signal baseline to drift as the battery discharged.

Overall, the project validated the core mechanical, electrical, and firmware concepts. However, the prototype did not fully meet the durability, heat resistance, responsiveness, and reliability requirements of the intended firefighting application.

To improve the design in the future, more research should be conducted on the materials used to better address the persona’s constraints. The materials should resist deformation from heat and prevent heat transfer to the user's body due to the likelihood that the persona will need to use the prosthetic during a fire. Additionally, the material of the palm should be adapted to provide greater friction. The current, smooth, plastic palm makes it easy for objects to slide out of the prosthetic clutch. A softer material with greater friction will allow the prosthetic to better conform to objects. Currently, the strength of the locking mechanism relies on the dog clutch’s ability to prevent the base axle from rotating and how well the dog clutch stays in the intended position. The plate of the clutch is secured to the axle through a nut and bolt, to tightly close the plate around the axle, and superglue. Unfortunately, if the torque applied by the object due to its weight exceeds the strength of dog clutch connection, the plate slips on the axle, and the fingers can move. Altering the connection method by drilling through the axle and inserting a pin to securely prevent the disk from rotating freely from the axle will strengthen the locking mechanism. Additionally, the springs are the only components pulling the fingers inward. So, the grip strength of the design relies entirely on the strength of the string. The locking mechanism only prevents the fingers from sliding further back. Thus, a design that can support stiffer springs without impeding the locking mechanism will improve the grip force.

To reduce the delay caused by the 500 ms activity window while maintaining resistance to false triggers, future firmware could replace binary comparator triggering with continuous Analog-to-Digital Converter (ADC) sampling. Digital filtering and a shorter moving average could then be implemented in C++ to distinguish intentional muscle contractions from noise and improve the locking response. If the mechanical system is later redesigned to actively control finger movement, muscle contraction intensity could also be mapped to servo speed and grip force.

For the electrical subsystem, the analog front-end could be transferred from a hand-soldered perfboard to a multi-layer surface-mount device (SMD) PCB. This would reduce the enclosure volume, shorten signal paths, and decrease electromagnetic interference. A dedicated Low-Dropout (LDO) regulator could also provide low-noise power to the analog front-end, while a buck-boost converter could supply the servo motor. Together, these changes would provide more stable power as the battery discharges.

Lastly, to more closely resemble a natural human hand, additional curves could be added to the casing to reduce its boxy appearance. A skin-like cover could also conceal the mechanical components and provide a smoother, more realistic surface. More natural proportions, colors, and surface textures could further improve overall appearance.

References

[1] A. J. Vigotsky et al., "Translating surface electromyography to biomechanics," Frontiers in

Physiology, vol. 7, p. 319, Aug. 2016. [Online]. Available:

https://pmc.ncbi.nlm.nih.gov/articles/PMC4968852/

[2] Government of Canada, "Job Bank: Firefighter (NOC 42101) - Ontario Market Report," Job

Bank Canada, 2024. [Online]. Available:

https://www.jobbank.gc.ca/marketreport/occupation/6279/ON

[3] Ontario Fire Administration Inc., "Candidate Physical Ability Test (CPAT) Assessment,"

Fire Services Ontario, 2024. [Online]. Available:

https://www.fireontario.com/site/occupational-assessment-cpat

[4] CYBATHLON Team SAM, "Arm Prosthesis Race: Cybathlon Tasks and Technical

Challenges," Team SAM, 2024. [Online]. Available: https://team-sam.fr/en/cybathlon/

[5] R. Merletti and P. A. Parker, Electromyography: Physiology, Engineering, and Non-Invasive

Applications. Hoboken, NJ: IEEE Press / John Wiley & Sons, 2004.

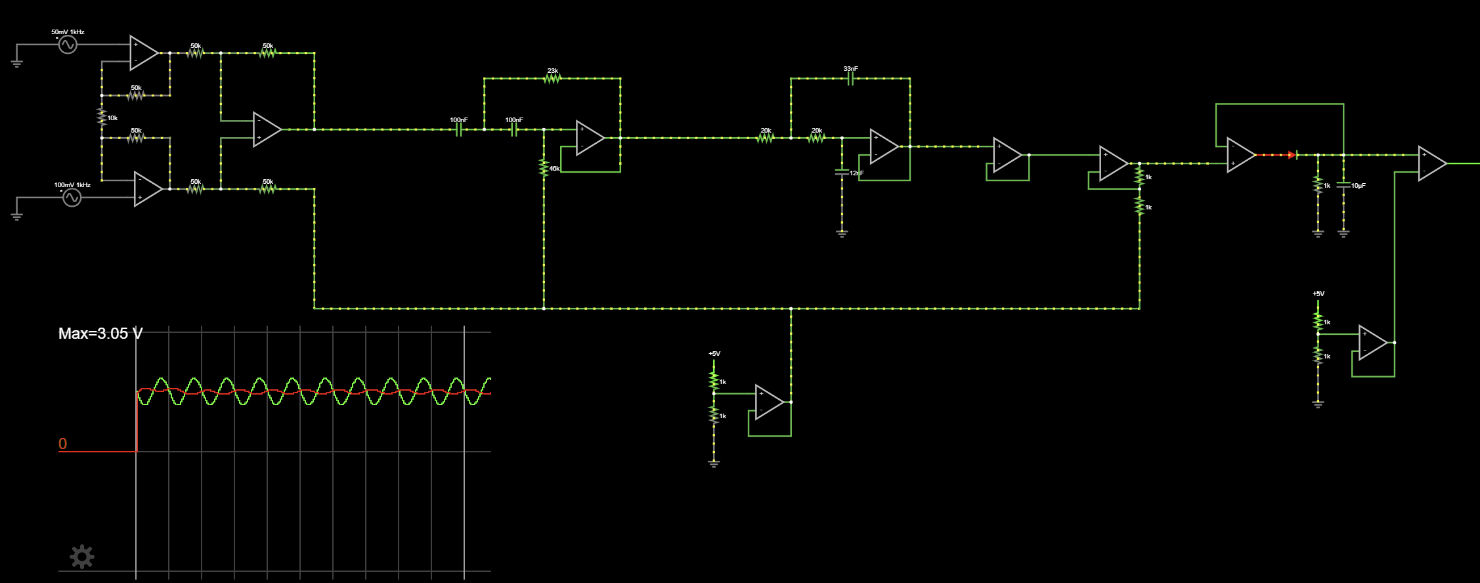
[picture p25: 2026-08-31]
electrical/schematic.png

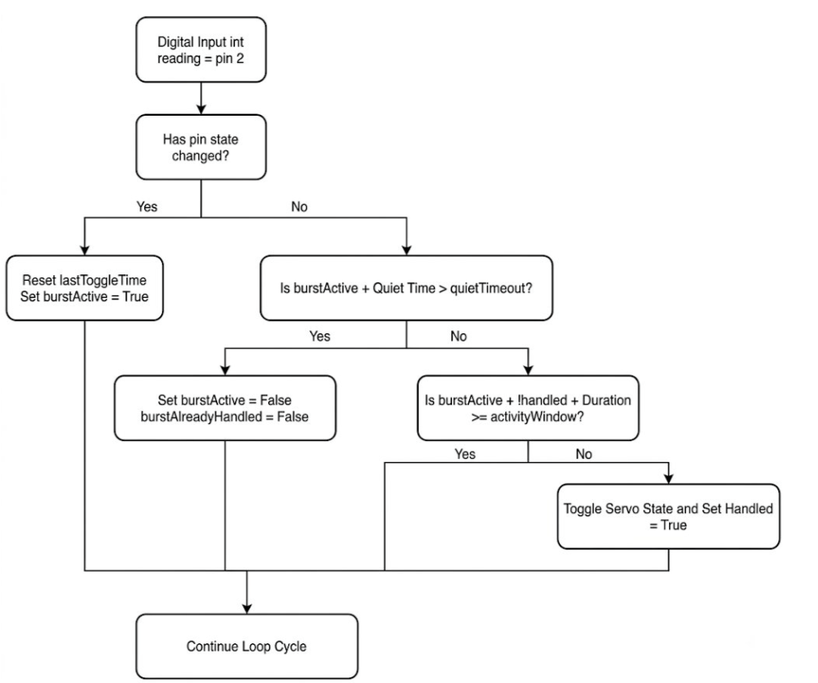
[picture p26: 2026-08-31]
firmware/flowchart.png

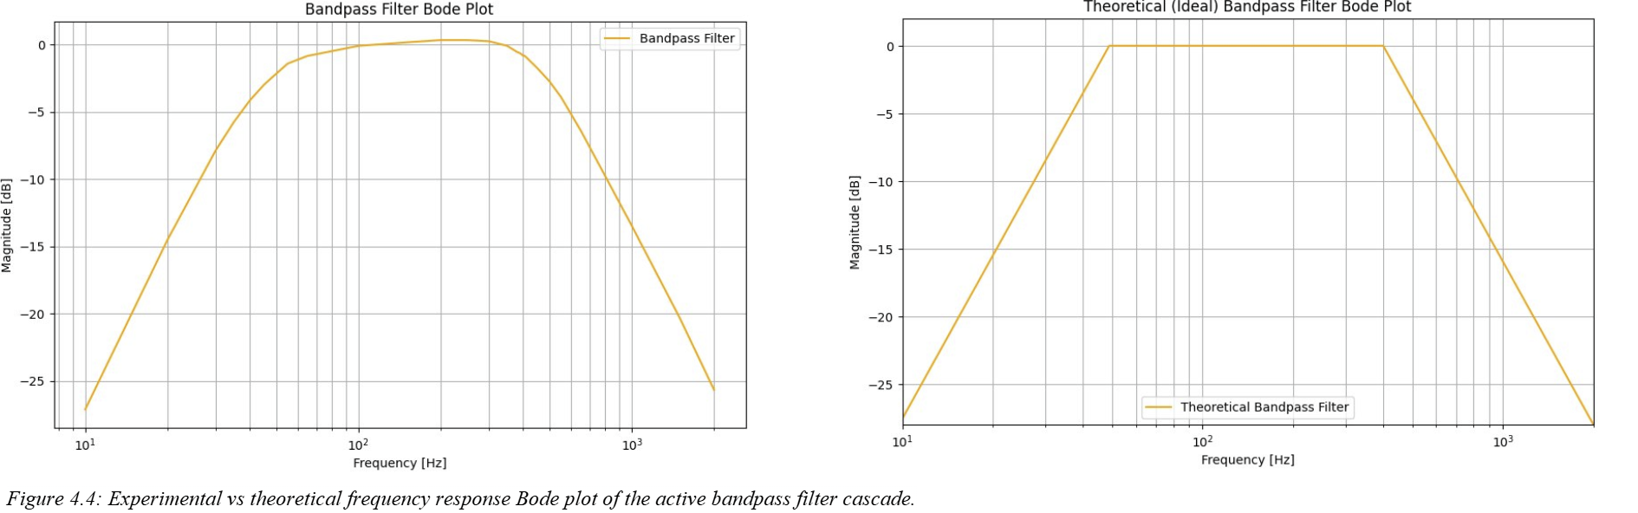
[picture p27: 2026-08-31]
electrical/bodeplots.png

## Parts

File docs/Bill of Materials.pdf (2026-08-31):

Component | Description / Spec | Q | Source | Cost | Manufacturing Method
Raw Material: Delrin Plate | Acetal plastic, 1/2" thickness (for Ratchet, Pawl, Cam) | 1 | McMaster-Carr | $35.00 | Manual Mill / Lathe fabrication
| ¼'’ thickness | | Laser cutting
Raw Material: Acrylic Sheet | Clear/Black Acrylic, 1/4" thickness (for inner structural plates) 3-5 layers, separate plates for phalanges | 1 | Engineering Shop | $15.00 | Laser Cutting
Worm & Worm Gear Set | Matched set (e.g., Module 1 or 24 DP, brass or steel) | 1 | McMaster-Carr | $45.00 | Off-the-shelf (No modification)
Palm Gear | Spur gear to mesh with internal finger drive | 1 | McMaster-Carr | $20.00 | Off-the-shelf
Miniature Chain & Sprockets | #25 or smaller roller chain + 2 matching sprockets (for finger link) | 1 | McMaster-Carr | $30.00 | Off-the-shelf, cut chain to length
Precision Axles / Shafts | 1/4" or 6mm D-shafting or Keyed Stainless Steel | 2 | McMaster-Carr | $12.00 | Cut to length on shop bandsaw
Flanged Bearings / Bushings | Shielded ball bearings matching chosen shaft diameter | 4 | McMaster-Carr | $5.00 | Press-fit into laser-cut acrylic plates
Pawl Spring | Small extension or torsion spring | 1-2 | McMaster-Carr (Assortment Pack) | $15.00 | Off-the-shelf

Aesthetic Outer Casing | PLA or PETG filament (ergonomic/anatomical hand shell) | 1 | WEEF / Sedra Student Design Centre | $10.00 | 3D Printing (FDM)
Position Motor | Given servo / stepper | 1 | Provided by Course | $0.00 | None (Mount to chassis)
Finger Drive Motor | Given DC motor | 1 | Provided by Course | $0.00 | None (Mount to chassis)
Custom Control PCB | Main board for EMG processing | 1 | JLCPCB / PCBWay (or local rapid proto) | $20.00 | Solder components to custom board

Dijiki, sign up with uwaterloo email

3d printing & assembly this week

Laser cutting > cutmypart.ca

Maybe on campus

Components

- Worm gear x1
- 3D print
- Main gear in palm (Ratchet)
- Acrylic laser cut/3D print
- Pawl
- 3D printed/laser cut
- Axle
- Order online, then cut
- Small gears in base of finger
- 3-D print
- They need a space to hold a chain (or string for rapid prototype)

- Top phalange
- Lazer cut/3D print
- It would look like a gear with a stick coming out of it
- Springs x2
- Online
- Chain
- Online
- Outside 3D printed

Amazo

- Chain
- https://www.amazon.ca/PLATT-1-Speed-8-Speed-114-Links-116-Links/dp/B091YYZYD1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 yJ2IjoiMSJ9.ALg4fSI8lgqoGLt2HN42rhUkd8gKPhdiKcRmSP26PWQKzzS 0SrRYqGbopwTBh5MrQS041bLfvrKpxdQdDsgGqx7I3FuIO8237KRkN3lYOiYQAf9715 H3j7epdlEypmml_1csLb3__jNVYEJkGUlx-0n33237ZVjhToliPFfC6iSFhGGnXrEaYoaQYYf2-kP3WqwuZVrRAr4t3q_6aLkhZzKNBhGpK61v6ed2-lI8aB6rqNM1Taop29zUSyJNXOUlZrsNKjDL-KrZqw7XhIDG-8WsvGEb6P2Yzd5Ftq4fA.Zkxq3OnbuVJxu3GqyHoERLmuFnX2OBzIXVjHqthVXxU&dib_ta g=se&keywords=bike%2B11%2Bchain&qid=1784040153&sprefix=bike%2 B11%2Bchain%2Caps%2C135&sr=8-2-spons&sp_csd=d2lkZ2V0TmFtZT1zcF9hdGY&th=1 (https://www.amazon.ca/PLATT-1-Speed-8-Speed-114-Links-116-Links/dp/B091YYZYD1?sp_csd=d2lkZ2V0TmFtZT1zcF9hdGY)
- Make sure to get 11-speed
- $23.98
- springs
- Worm gear
- Ratchet
- Pawl
- Small gears in base of finger
- Top phalange

*Things to keep in mind:

- Main axle in hand only rotates about 75 degrees

- Worm gear

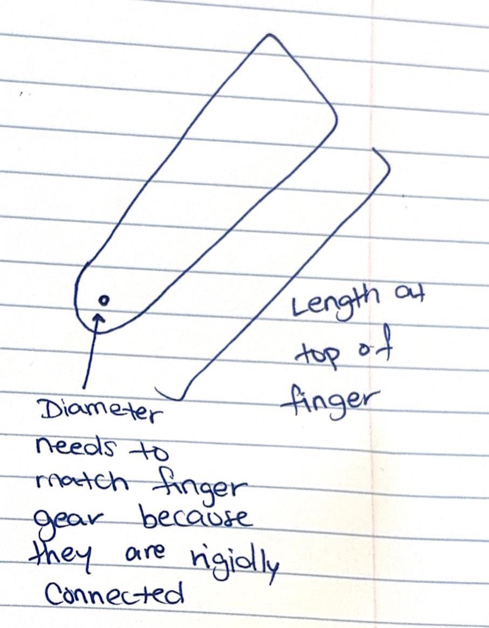
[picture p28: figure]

Hilda

- Finger gears x4 **Note we are buying a 11-speed chain, ensure the dimensions of the gear fit this change

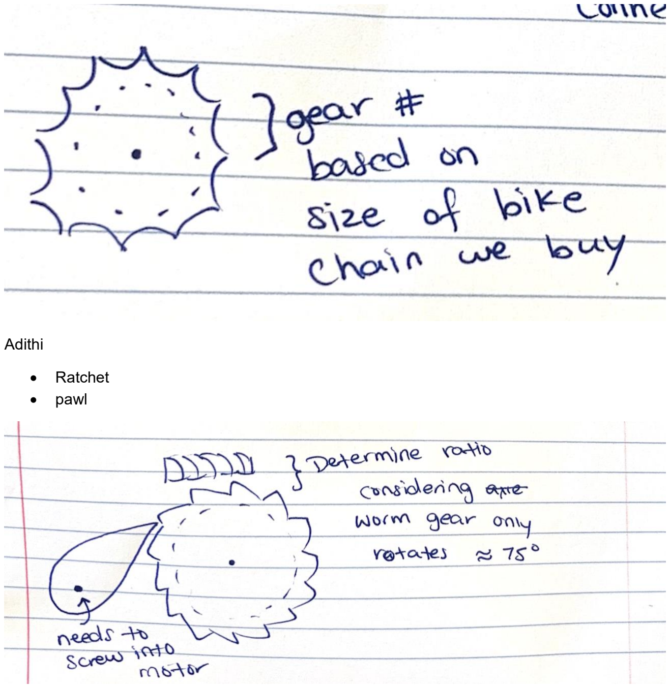
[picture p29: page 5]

Adithi

- Ratchet
- pawl

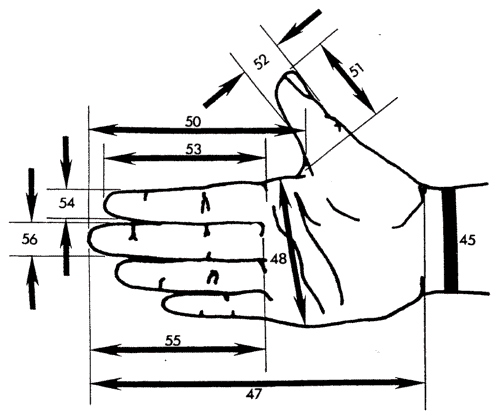
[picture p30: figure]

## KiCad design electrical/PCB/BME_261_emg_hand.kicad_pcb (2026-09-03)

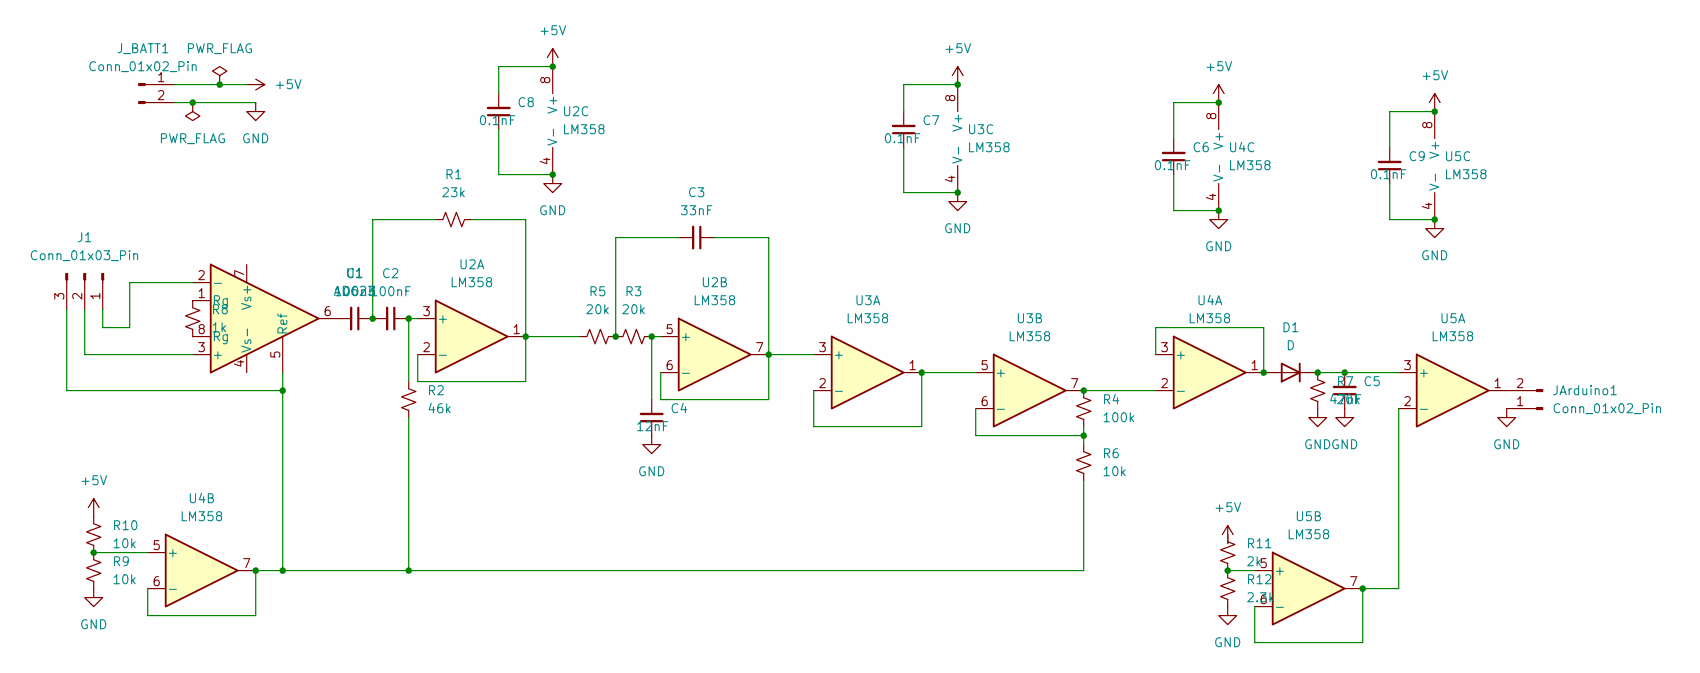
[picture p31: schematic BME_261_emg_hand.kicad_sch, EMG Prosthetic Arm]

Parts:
C1, C2: 100nF; C_Disc_D5.0mm_W2.5mm_P5.00mm
C3: 33nF; C_Disc_D5.0mm_W2.5mm_P5.00mm
C4: 12nF; C_Disc_D5.0mm_W2.5mm_P5.00mm
C5: 47nF; C_Disc_D5.0mm_W2.5mm_P5.00mm
C6, C7, C8, C9: 0.1nF; C_Disc_D5.0mm_W2.5mm_P5.00mm
D1: D; D_DO-35_SOD27_P7.62mm_Horizontal
J1: Conn_01x03_Pin; PinHeader_1x03_P2.54mm_Vertical
JArduino1: Conn_01x02_Pin; PinHeader_1x02_P2.54mm_Vertical
J_BATT1: Conn_01x02_Pin; PinHeader_1x02_P2.54mm_Vertical
R1: 23k; R_Axial_DIN0207_L6.3mm_D2.5mm_P7.62mm_Horizontal
R2: 46k; R_Axial_DIN0207_L6.3mm_D2.5mm_P7.62mm_Horizontal
R3, R5, R7: 20k; R_Axial_DIN0207_L6.3mm_D2.5mm_P7.62mm_Horizontal
R4: 100k; R_Axial_DIN0207_L6.3mm_D2.5mm_P7.62mm_Horizontal
R6, R9, R10: 10k; R_Axial_DIN0207_L6.3mm_D2.5mm_P7.62mm_Horizontal
R8: 1k; R_Axial_DIN0207_L6.3mm_D2.5mm_P7.62mm_Horizontal
R11: 2k; R_Axial_DIN0207_L6.3mm_D2.5mm_P7.62mm_Horizontal
R12: 2.3k; R_Axial_DIN0207_L6.3mm_D2.5mm_P7.62mm_Horizontal
U1: AD623; DIP-8_W7.62mm_SMDSocket_SmallPads
U2, U3, U4, U5: LM358; DIP-8_W7.62mm

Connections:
+5V: C6.2, C7.2, C8.2, C9.2, J_BATT1.1, R10.2, R11.2, U2.8 (V+), U3.8 (V+), U4.8 (V+), U5.8 (V+)
GND: C4.1, C5.1, C6.1, C7.1, C8.1, C9.1, JArduino1.1, J_BATT1.2, R7.1, R9.1, R12.1, U2.4 (V-), U3.4 (V-), U4.4 (V-), U5.4 (V-)
unnamed: C1.1, C2.2, R1.2
unnamed: C1.2, U1.6
unnamed: C3.2, R3.1, R5.1
unnamed: D1.2 (A), U4.1, U4.3 (+)
unnamed: C5.2, D1.1 (K), R7.2, U5.3 (+)
unnamed: J1.1, U1.2 (-)
unnamed: J1.2, U1.3 (+)
unnamed: J1.3, R2.1, R6.1, U1.5 (Ref), U4.6 (-), U4.7
unnamed: JArduino1.2, U5.1
unnamed: R8.1, U1.8 (Rg)
unnamed: R8.2, U1.1 (Rg)
unnamed: C2.1, R2.2, U2.3 (+)
unnamed: R1.1, R5.2, U2.1, U2.2 (-)
unnamed: C4.2, R3.2, U2.5 (+)
unnamed: C3.1, U2.6 (-), U2.7, U3.3 (+)
unnamed: U3.1, U3.2 (-), U3.5 (+)
unnamed: R4.1, R6.2, U3.6 (-)
unnamed: R4.2, U3.7, U4.2 (-)
unnamed: R9.2, R10.1, U4.5 (+)
unnamed: U5.2 (-), U5.6 (-), U5.7
unnamed: R11.1, R12.2, U5.5 (+)

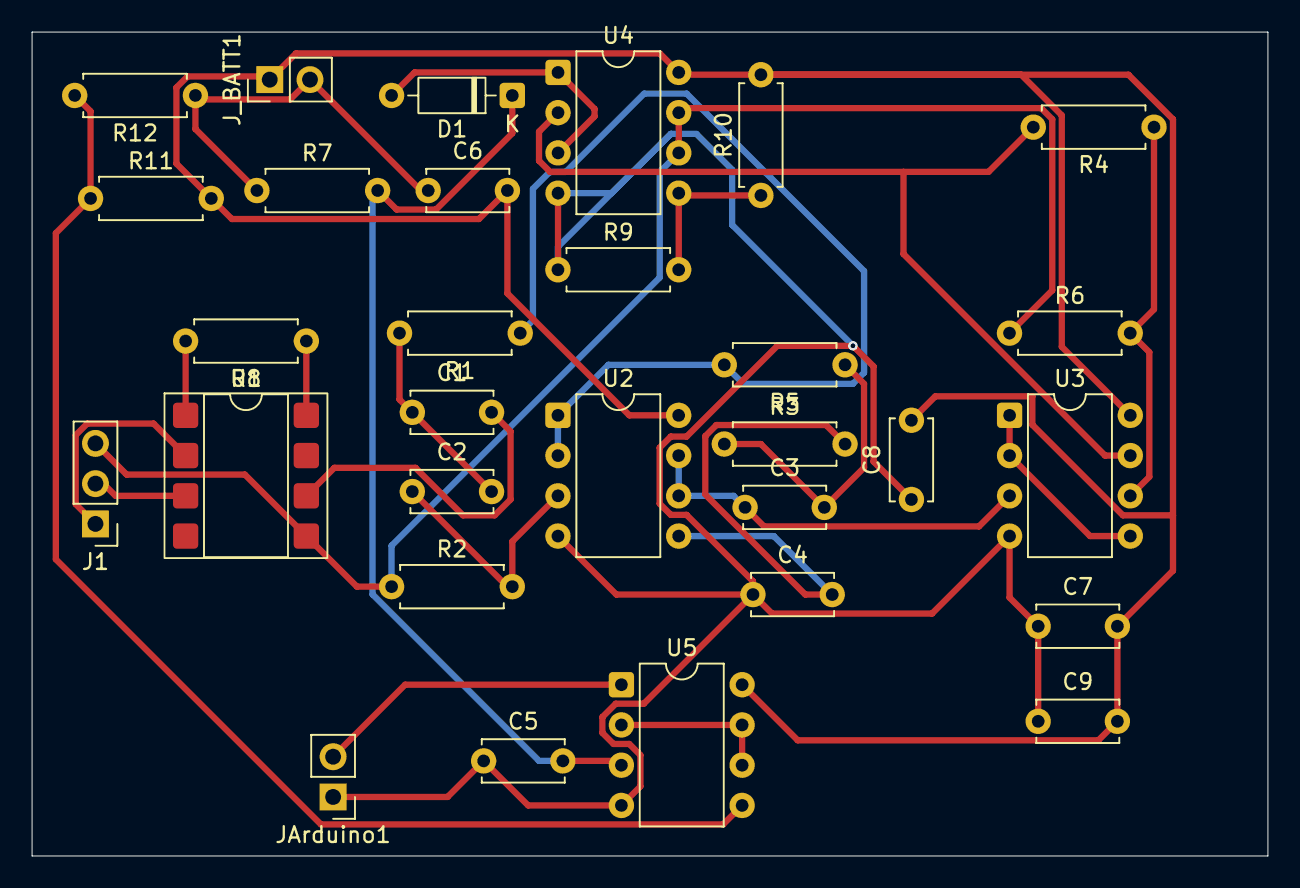
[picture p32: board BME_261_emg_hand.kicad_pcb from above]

Board: 2 copper layers, 78.0 x 52.0 mm, 30 parts (0 on the bottom side), 23 nets.

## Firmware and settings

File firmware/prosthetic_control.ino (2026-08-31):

#include <Arduino.h>
#include <Servo.h>

// input signal(0/5V) > Arduino 2
// input GND > Arduino GND
// SERVO signal > Arduino 9
// Servo red cable > 5V (battery maybe)
// Servo black/brown cable > GND

Servo myServo;

const int servoPin = 9;
const int inputPin = 2;

const unsigned long activityWindow = 500;  // ms - how long a burst must persist before counting as "signal detected"
const unsigned long quietTimeout = 400;      // ms - how long with NO toggling before we consider it "rest"

int lastReading = LOW;
unsigned long lastToggleTime = 0;       // last time the input actually changed state
unsigned long burstStartTime = 0;       // when this burst of activity started
bool burstActive = false;               // are we currently inside a burst?
bool burstAlreadyHandled = false;       // prevents re-triggering multiple times within one burst

bool servoIsFlexed = false;

void setup()
{
  pinMode(inputPin, INPUT);

  myServo.attach(servoPin);
  myServo.write(0);
}

void loop()
{
  int reading = digitalRead(inputPin);
  unsigned long now = millis();

  // detect toggling (any change counts as "activity", not just rising edges)
  if (reading != lastReading)
  {
    lastToggleTime = now;

    if (!burstActive)
    {
      burstActive = true;
      burstStartTime = now;
      burstAlreadyHandled = false;
    }
  }

  // if we've gone quietTimeout ms with no toggling, the burst has ended
  if (burstActive && (now - lastToggleTime > quietTimeout))
  {
    burstActive = false;
    burstAlreadyHandled = false;
  }

  // if we're in an active burst that's lasted long enough, and haven't handled it yet, trigger the toggle
  if (burstActive && !burstAlreadyHandled && (now - burstStartTime >= activityWindow))
  {
    servoIsFlexed = !servoIsFlexed;

    if (servoIsFlexed)
    {
      myServo.write(90);
    }
    else
    {
      myServo.write(0);
    }

    burstAlreadyHandled = true; // don't re-trigger again until this burst ends and a new one starts
  }

  lastReading = reading;
}

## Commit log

2026-08-31 Add Arduino firmware for servo control based on input
2026-08-31 Rename Screenshot 2026-08-31 132650.png to flowchart
2026-08-31 Add Falstad circuit diagram
    Added a Falstad circuit diagram with various components including resistors, capacitors, and voltage sources.
2026-08-31 Rename Screenshot 2026-08-31 133829.png to schematic.png
2026-09-03 Add PCB and grounding details to README
